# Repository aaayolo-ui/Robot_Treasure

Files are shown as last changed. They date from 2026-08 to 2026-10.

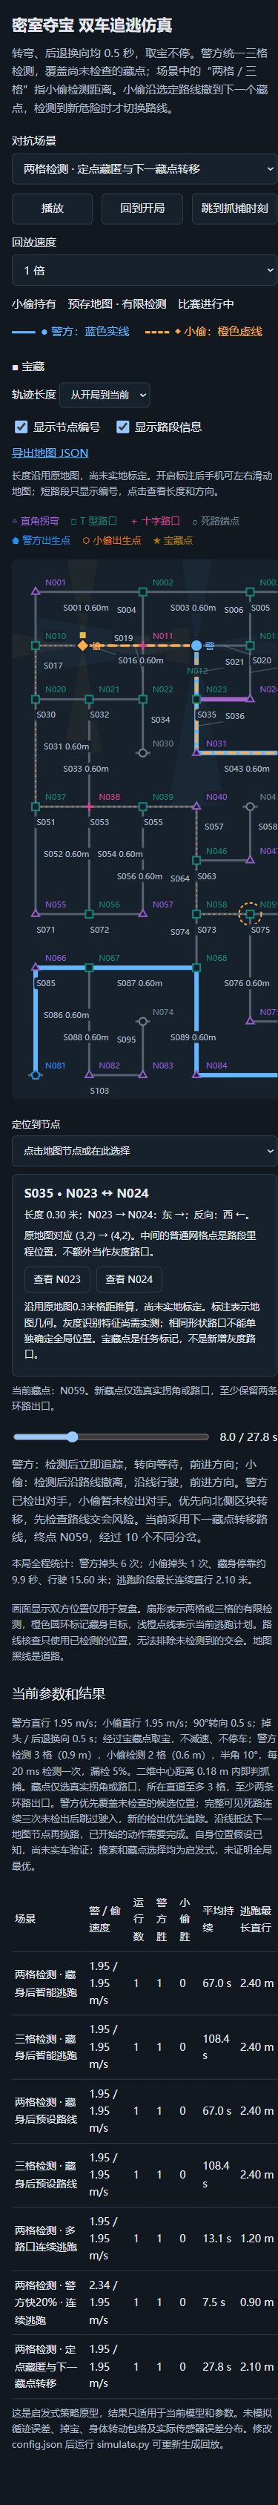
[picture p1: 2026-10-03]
Tools/TreasurePursuitSimulator/qa/annotations-mobile.jpg

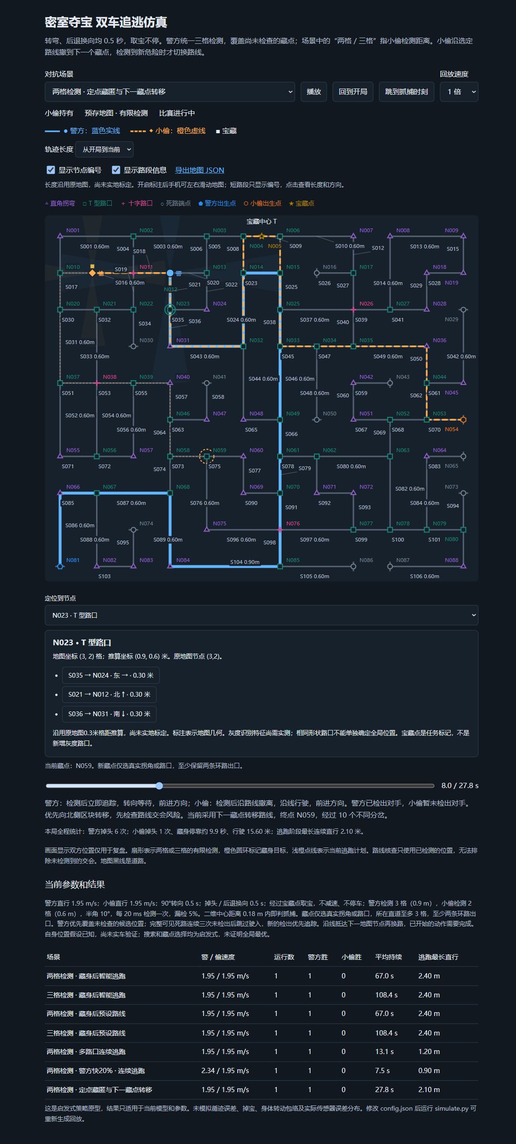
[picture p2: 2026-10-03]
Tools/TreasurePursuitSimulator/qa/annotations-desktop.jpg

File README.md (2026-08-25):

# Robot_Treasure

基于 STM32 的四轮差速自主移动机器人，用于 2026 江苏省大学生机器人大赛“密室夺宝”项目。

## 项目基线

项目以稳定循迹、可靠路口判断和可恢复故障处理为优先级，不追求极限速度。系统不使用 Jetson、摄像头、YOLO 或 ROS。

| 项目 | 当前确定方案 |
|---|---|
| 主控 | STM32F103RCT6 开发板 |
| 底盘 | R5 铝合金四驱底盘，2 mm 铝合金底板，约 190 mm × 198 mm × 72 mm |
| 动力 | MC520P30_12V 永磁有刷编码器减速电机 ×4，配 65 mm 黑色大摩擦力轮胎 ×4 |
| 驱动 | MD240A 四路 TB6612FNG 编码器电机驱动板 ×1；四个通道分别驱动四个车轮 |
| 电源 | LB326E 12 V 2600 mAh 3S 锂电池、12.6 V 1.5 A 配套充电器、3 A 多路 DC-DC |
| 循迹 | NCHD12 12 路灰度传感器 ×2，经同一条 I²C 总线连接 |
| 对手检测 | AI-1811 单模块基础 UART 读取已完成；前、后、左、右四方向的多模块方案尚未最终锁定 |
| 机构与提示 | 前后黑色 ABS 板、强力磁铁、LED、有源蜂鸣器 |

## 关键控制原则

- 前 NCHD12 是前进循迹和主要路口判断的默认输入；后 NCHD12 用于后退循迹和逃跑模式。
- 前、后模块保留独立数据和物理方向，不能简单拼成横向连续 24 路；默认不运行两个相互冲突的独立循迹 PID。
- 四个电机独立输出、独立编码器反馈；基础阶段同侧前后轮可使用相同目标速度，但不能并联到同一驱动通道。
- 电机的额定理论线速度约 0.99 m/s，初期软件目标速度限制在约 0.3～0.5 m/s，并采用 PWM 限制、斜坡和速度闭环。

## 供电关系

```text
3S 锂电池
    │
    ├── 总开关 ── 保险丝 ── 动力支路 ── MD240A ── Motor_FL / Motor_RL / Motor_FR / Motor_RR
    │
    └── 控制支路 ── 3A 多路 DC-DC
                         ├── 5V → STM32 开发板及 5V 传感器
                         └── 3.3V → 编码器及 3.3V 模块
```

电机仅由电池直接向 MD240A 的 VM 端供电，不能经过 DC-DC。整车所有模块必须共地；MD240A 板载 3.3 V / 5 V 不作为整车主要控制电源，两个稳压模块的输出不得直接并联。

## 状态与下一步

已购买：R5 铝合金四驱底盘、MC520P30_12V 编码器电机 ×4、65 mm 黑色轮胎 ×4、前后黑色 ABS 板、AI-1811 ToF 激光测距模块 ×1、USB 转 TTL 模块 ×1。USB 转 TTL 用于电脑串口测试；12B 已将 AI-1811 直接连接 STM32 完成单模块基础读取。

已完成技术选型、但购买状态须按项目记录确认：MD240A、LB326E 电池、配套充电器、3 A 多路 DC-DC、NCHD12 ×2。STM32F103RCT6 开发板与 ST-Link V2 的实际购买状态也仍需项目记录确认。

当前敌方检测仍处于方案验证阶段：AI-1811 单模块的 UART 通信、帧格式、校验和距离字段已完成实物原始数据验证；普通红外单路接口（12A，`VCC→3.3V`、`OUT→PB14`、低电平有效）已完成近距离障碍/物体检测基础验证，并在 13A 完成“连续障碍检测→停车约 200 ms→30 RPM 后退约 1 s→自动停车”的基础车辆联动验证。
普通红外仍暂时作为备用和对比测试使用，不代表最终敌方机器人检测、最终安装或最终整车方案；前、后、左、右四方向的多模块数量、安装及通信方案仍待后续验证，距离精度标定未执行。

## 文档

- [总体方案设计](Docs/03_总体方案设计.md)
- [硬件清单](Docs/04_硬件清单.md)
- [STM32 软件架构设计](Docs/05_STM32软件架构设计.md)
- [开发记录](Docs/06_开发记录.md)
- [团队协作与 Git 分支说明](Docs/07_团队协作与Git分支说明.md)

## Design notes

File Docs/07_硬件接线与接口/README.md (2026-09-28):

# Robot_Treasure 硬件接线与接口

本目录是项目级的实体接线、STM32 引脚占用与扩展规划的唯一维护入口；不属于任何单一测试工程，也不存放硬件驱动代码。
当前灰度方向参考工程为 [`Gray12_VehicleDirection_Test`](../../STM32/Keil_Project/Gray12_VehicleDirection_Test)，已完成 11C 灰度安装方向与车辆横向误差符号实机确认。
AI-1811 单模块基础 UART 读取的历史参考工程为 [`Laser12B_AI1811_Raw_Uart_Test`](../../STM32/Keil_Project/Laser12B_AI1811_Raw_Uart_Test)；当前整车不再使用该模块，原 PA3 占用已经释放。
普通红外已由 [`Infrared_Raw_Test`](../../STM32/Keil_Project/Infrared_Raw_Test) 完成 12A 基础读取，并由 [`Infrared13A_ObstacleReverse_Test`](../../STM32/Keil_Project/Infrared13A_ObstacleReverse_Test) 完成基础障碍触发后退联动验证。

## 当前基线

台架已使用的供电路径为：3S 锂电池正、负极分别接入 MD240A `VIN/VM`、`GND`；MD240A `VOUT 5V`、`GND` 分别接入 STM32 开发板 `5V`、`GND`；STM32 `5V/GND` 再接第一块 NCHD12 的 `VCC/GND`。四路电机、四路编码器、第一块 NCHD12、CH340 调试串口、ST-Link SWD 与板载按键均已有实际连接或实机验证记录，详见下表文档。

```text
3S 电池 ──> MD240A VIN/VM ──> 四路电机
                 │ VOUT 5V
                 └────────────> STM32 5V ──> NCHD12(0x20)
所有已连接模块 GND ───────────────────────> 共地
```

### 11C/11D 当前车辆坐标与单轮方向基线

- 当前车头为 11C 重新定义后的车头；物理轮位为 FL=B、FR=A、RL=D、RR=C。
- 灰度模块 P12 侧对应 `VEHICLE_LEFT`，P1 侧对应 `VEHICLE_RIGHT`。
- 灰度标签坐标保持 P1 侧为负、P12 侧为正；车辆横向误差使用 `vehicle_error_x100 = -label_position_x100`，即车辆左为负、右为正。
- 11D-1 已实机确认车辆前进方向：B/FL→ELEC_REV、A/FR→ELEC_REV、D/RL→ELEC_FWD、C/RR→ELEC_FWD；车辆后退使用相反电气方向。
- 前进时原始编码器符号对应逻辑符号为 B/D=+1、A/C=-1。11D-2 已实机确认新车头下的前进直行：左侧分组 B+D、右侧分组 A+C，四轮独立速度 PI 在目标最终 80 RPM 下稳定至约 77～79 RPM，整体左右平均转速差约 0.2 RPM，无长期 PI 饱和；后退、转向和循迹闭环仍待独立验证。
- PWM=180/999 的单轮测试下，四路均可连续转动；没有 B 专用固定 PWM 补偿。旧测试工程及其历史阶段记录可能使用旧车头映射，不能直接作为当前轮位控制基线。
- 12A/13A 已实机确认普通红外单路接口为 `VCC→3.3V`、`GND→GND`、`OUT→PB14`；PB14 使用 `GPIO Input`、`GPIO_NOPULL`，低电平表示 `DETECTED`、高电平表示 `CLEAR`。
  13A 已验证连续障碍检测可触发一次“停车约 200 ms→30 RPM 后退约 1 s→自动停车”的基础联动；该引脚仍仅为测试接口，不是最终整车永久分配。
- 当前计划保留 PB14 作为前向红外，并新增左/后/右三路普通红外：左 `PA3`、后 `PB15`、右 `PA11`。三路新增分配均尚未接线验证；PA11、PB15 接线前还须确认开发板实体引出。

## 文档导航

- [01_已验证硬件接线总表.md](01_已验证硬件接线总表.md)：已连接且已使用或验证的供电、模块与信号接线；AI-1811 条目仅保留历史验证事实，并注明当前已拆除。
- [02_STM32引脚占用总表.md](02_STM32引脚占用总表.md)：以最新参考工程 `.ioc` 为准的 STM32 引脚占用。
- [03_后续硬件扩展预留.md](03_后续硬件扩展预留.md)：尚未接入或尚未验证的硬件计划，不能当作现状使用。

## 状态说明

| 状态 | 定义 |
|---|---|
| 已实机验证 | 已实际接线，并有实机测试或可追溯验证记录。 |
| 已连接但具体参数待确认 | 接线/信号已使用，但电压、极性、针序等参数尚无独立可靠记录。 |
| 仅软件配置 | 当前 `.ioc` 或代码配置了资源，不单独代表实体接线已完成。 |
| 仅后续计划 | 尚未实机接入和验证；只能记录在 `03` 中。 |

## 修改规则

- 新增硬件前先检查 [02_STM32引脚占用总表.md](02_STM32引脚占用总表.md)，不得直接使用已占用引脚。
- 改动引脚时必须同步修改 `.ioc`、源代码驱动和本目录文档。
- 未完成实机测试的接线只能写入 `03`；完成实机测试后，才能移入 `01`。
- 文档与实物不一致时，停止上电并重新核对；不得凭猜测接线。

## 安全规则

- 所有模块必须共地；禁止带电插拔 I2C、编码器和电源线。
- 当前由 MD240A `VOUT 5V` 给 STM32 供电时，外部 DC-DC 输出不得同时并联到 STM32 `5V`。
- 电池 `VIN/VM` 不得接入 STM32；电机动力电源不得经过 STM32 或外部 5V 降压输出。
- CH340 只接串口信号和 GND 时，不接其 `5V/3.3V` 输出；ST-Link、CH340、MD240A VOUT 与后续 DC-DC 不能同时作为 STM32 供电源。

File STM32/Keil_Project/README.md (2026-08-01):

# Keil_Project

用于存放 Keil5 工程文件。

## 后续操作

`CubeMX 生成工程 → 使用 Keil5 打开 → 添加 User/Hardware/Algorithm/Control 文件 → 编译 → ST-Link 下载`

> 当前未指定 STM32 型号，因此暂不创建 `.uvprojx` 工程。

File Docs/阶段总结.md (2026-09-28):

# 阶段总结

本文件按开发顺序记录阶段结论。除明确标为实机确认的内容外，其余仅代表工程实现或编译状态，不补写缺失的硬件测试事实。

## 01｜Motor_A_Test

### 对应工程

`STM32/Keil_Project/Motor_A_Test`

### 阶段目标

建立 A 路电机正转、反转、停止和驱动使能的基础测试。

### 关键配置

电机驱动默认停止，PWM 为 0，驱动板默认禁用；方向切换需先停止。

### 实际测试结果

本次汇总未检索到可独立引用的原始硬件测试记录。

### 已知问题

硬件测试原始数据待后续补录。

### 最终结论

部分通过：基础工程已完成；进入下一阶段前应保留并补充对应的实机记录。

### 下一阶段

Motor_A_Encoder_Test。

## 02｜Motor_A_Encoder_Test

### 对应工程

`STM32/Keil_Project/Motor_A_Encoder_Test`

### 阶段目标

验证 A 路编码器计数、方向和转速计算基础。

### 关键配置

采用定时器编码器模式，转速以整数 `rpm_x10` 表示。

### 实际测试结果

本次汇总未检索到可独立引用的原始硬件测试记录。

### 已知问题

硬件测试原始数据待后续补录。

### 最终结论

部分通过：编码器基础工程已完成；需以原始实测记录补充硬件结论。

### 下一阶段

Motor_A_PwmRpm_Test。

## 03｜Motor_A_PwmRpm_Test

### 对应工程

`STM32/Keil_Project/Motor_A_PwmRpm_Test`

### 阶段目标

观察 A 路电机 PWM 与转速的关系，为闭环参数选择提供基础。

### 关键配置

使用 A 路电机和编码器的 PWM/RPM 测试链路。

### 实际测试结果

已实际观察到：B 电机在相同开环 PWM 下较慢；该现象已转入 P001 持续观察。

### 已知问题

B 的偏慢原因尚未完全确认。

### 最终结论

部分通过：PWM/RPM 对比为后续独立闭环提供了依据。

### 下一阶段

Motor_A_SpeedPid_Test。

## 04｜Motor_A_SpeedPid_Test

### 对应工程

`STM32/Keil_Project/Motor_A_SpeedPid_Test`

### 阶段目标

验证单电机定点速度 PI 控制。

### 关键配置

Kp=0.80、Ki=0.25；定点计算、积分限幅、防积分饱和；控制周期 100 ms。

### 实际测试结果

已实机验证通过的 PI 算法、参数、启动处理、停止积分清零和目标/测量单位，后续被四轮工程复用。

### 已知问题

本次汇总未包含该阶段完整原始串口曲线。

### 最终结论

通过：可进入四路底盘模块化阶段。

### 下一阶段

Four_Motor_Base。

## 05｜Four_Motor_Base

### 对应工程

`STM32/Keil_Project/Four_Motor_Base`

### 阶段目标

建立四路电机、四路编码器及安全默认状态的模块化基础。

### 关键配置

四路 PWM、编码器和驱动板 STBY；上电 PWM=0、方向 GPIO 为低、驱动禁用。

### 实际测试结果

已统一采用 1560 count/rev；B 的人工标定约 1565.1 count/rev，差异较小。

### 已知问题

B 的偏慢并非主要由编码器每圈计数差异造成，见 P001、P002。

### 最终结论

通过：可进入四路通道测试。

### 下一阶段

Four_Motor_Channel_Test。

## 06｜Four_Motor_Channel_Test

### 对应工程

`STM32/Keil_Project/Four_Motor_Channel_Test`

### 阶段目标

验证四路电机与四路编码器通道的独立性。

### 关键配置

每个硬件编码器 delta 在一个采样周期内仅读取一次；各通道独立显示与控制。

### 实际测试结果

本次汇总未检索到可独立引用的原始硬件测试记录。

### 已知问题

原始通道测试数据待后续补录。

### 最终结论

部分通过：工程已作为后续底盘工程的来源；硬件原始记录仍需补充。

### 下一阶段

Four_Motor_Chassis_Test。

## 07｜Four_Motor_Chassis_Test

### 对应工程

`STM32/Keil_Project/Four_Motor_Chassis_Test`

### 阶段目标

确认四轮车体逻辑方向、物理轮位和编码器符号。

### 关键配置

FL=D、FR=C、RL=B、RR=A；逻辑前进时 D/C 电气正转、B/A 电气反转；A=-1、B=+1、C=-1、D=+1。

### 实际测试结果

该方向映射与逻辑编码器符号已作为后续四轮闭环和落地测试的验证基础。

### 已知问题

未在本次汇总中补录各动作的原始实测数据。

### 最终结论

通过：可进入四轮独立速度闭环阶段。

### 下一阶段

Four_Motor_SpeedPid_Test（10E）。

## 08｜Four_Motor_SpeedPid_Test（10E）

### 对应工程

`STM32/Keil_Project/Four_Motor_SpeedPid_Test`

### 阶段目标

建立四个相互独立的车轮速度 PI 控制器，并验证前进、后退与原地转向的逻辑速度符号。

### 关键配置

四个独立 PI 实例；Kp=0.80、Ki=0.25、100 ms 控制周期；四轮反馈和逻辑 PWM 均由 Chassis 层统一映射。

### 实际测试结果

四轮独立速度 PI 已实机验证；停止/禁用状态下的反馈刷新已统一，单轮速度与左右平均值使用同一 Chassis 反馈帧。

### 已知问题

紧急停止后首帧可能显示实际惯性速度，见 P004。

### 最终结论

通过：可进入落地低速直线测试。

### 下一阶段

Four_Motor_GroundStraight_Test（10F）。

## 09｜Four_Motor_GroundStraight_Test（10F）

### 对应工程

`STM32/Keil_Project/Four_Motor_GroundStraight_Test`

### 阶段目标

在底盘落地条件下观察四轮独立闭环前进、后退、起停安全性和左右速度差异。

### 关键配置

- 前进四轮目标：+80.0 RPM；后退四轮目标：-80.0 RPM。
- 软启动：4.0 RPM / 100 ms，0 到 80 RPM 约需 2.0 秒。
- PWM 测试上限：300；最大运行时间：3 秒，到时自动停止。
- Kp=0.80，Ki=0.25，控制周期=100 ms，堵转持续时间=1500 ms。
- 停止或禁用时 PI 清零但编码器反馈继续更新；不使用 B 轮或左右固定补偿。

### 实际测试结果

- 前进方向正确，后退方向正确。
- 前进约 50 cm 时向右偏约 2～3 cm。
- 后退向左后方返回，轨迹大致回到原来的位置。
- 未出现原地旋转、单轮反转或明显失控。

### 已知问题

存在稳定轻微右偏，当前可接受，见 P005。

### 最终结论

通过：可以进入灰度传感器基础读取阶段。

### 下一阶段

11A｜灰度传感器基础读取测试。

## 10｜11A｜12路灰度传感器 I2C 基础读取与通道映射

### 对应工程

`STM32/Keil_Project/Gray12_I2C_BasicRead_Test`

### 阶段目标

验证 12 路灰度模块的 I2C 基础通信、物理通道顺序、黑白极性和黑色通道数量统计，并保持电机处于安全禁用状态。

### 关键配置

- I2C1 使用 PB8/PB9 重映射，频率为 100 kHz；模块 7 位地址为 `0x20`，HAL 调用使用 `addr7 << 1`。
- 使用 PCA9555-compatible 访问方式：输入配置寄存器为 `0x06`、`0x07`，输入数据寄存器为 `0x00`、`0x01`。
- `RAW16` 为完整 16 位原始数据，`GRAY12 = RAW16 & 0x0FFFU`；B12～B15 不属于灰度通道。
- 通道映射为 P1=B0、P2=B1，依次至 P12=B11；黑色=1，白色=0。
- 结构分层：Core 仅保留 CubeMX 外设初始化和 App 调用；Hardware 包含 MotorDriver、Encoder、Key、NCHD12、UartDebug；User 为 `App_Gray12BasicRead`。
- 电机安全状态：Driver 禁用、STY 低电平、四路 PWM 为 0，未启动速度 PI。

### 实际测试结果

- 全白：`RAW16=0xF000`、`GRAY12=0x000`、`BLACK_COUNT=0`，P1～P12 均为 0。
- 全黑：`RAW16=0xFFFF`、`GRAY12=0xFFF`、`BLACK_COUNT=12`，P1～P12 均为 1。
- 仅 P1 为黑：`GRAY12=0x001`、`BLACK_COUNT=1`。
- 仅 P6 为黑：`GRAY12=0x020`、`BLACK_COUNT=1`。
- 仅 P12 为黑：`GRAY12=0x800`、`BLACK_COUNT=1`。
- 串口输出正常，P1～P12 通道顺序和 `BLACK_COUNT` 统计正确，灰度数据变化与模块指示灯一致。
- 测试全过程电机未运动；Keil 编译结果为 0 Error(s)、0 Warning(s)。

### 已知问题

曾发生设备地址可应答但 PCA9555-compatible 寄存器读写失败的情况；最终复测未持续出现，唯一根本原因尚未确认，详见 P007。

### 最终结论

通过：已完成硬件验证，可以进入后续灰度位置计算阶段。

### 下一阶段

灰度位置计算基础验证（加权位置算法）。

## 11｜11B｜12路灰度位置与横向误差计算

### 对应工程

`STM32/Keil_Project/Gray12_Position_Test`

### 阶段目标

基于 11A 已验证的单块 NCHD12 读取结果，验证 12 路二值灰度的加权位置、相对传感器中心的横向误差、无黑线和全黑状态判断；本阶段不执行巡线 PID、车轮差速修正、丢线搜索或路口识别。

### 软件结构与关键配置

- 工程以已验证可下载的 `Gray12_I2C_BasicRead_Test` 为完整模板复制，保留 `.uvprojx`、`.uvoptx`、ST-Link、SWD、Flash Algorithm 与下载配置；未修改引脚、时钟、I2C、USART、电机或编码器硬件配置，`.ioc` 仅改项目名称和文件名。
- `Core` 保留 CubeMX 初始化和 App 调用；`Hardware` 保留 MotorDriver、Encoder、Key、NCHD12、UartDebug；新增 `System/SystemTime`、纯算法 `Algorithm/GrayPosition` 和 `User/App_Gray12Position`。
- `GrayPosition` 不包含 HAL，不访问 I2C、GPIO、UART、定时器或电机，不使用 `float` 或 `double`；输入仅使用 `gray12` 低 12 位。
- 一个探头间距定义为 `100`，权重依次为：P1=-550、P2=-450、P3=-350、P4=-250、P5=-150、P6=-50、P7=+50、P8=+150、P9=+250、P10=+350、P11=+450、P12=+550。
- 坐标为传感器标签坐标：P1 一侧为负、P12 一侧为正，P6/P7 之间为 0；尚未绑定到车辆左/右方向。
- 黑色通道权重求和后除以黑色通道数量得到 `POSITION_X100`；中心目标为 0，因此 `ERROR_X100 = POSITION_X100`。
- `GRAY12=0x000` 为 `NO_LINE`、`VALID=0`；黑色通道数量 1～11 为 `VALID`、`VALID=1`；`GRAY12=0xFFF` 为 `ALL_BLACK`、`VALID=0`。无黑线和全黑均不伪装为有效中心位置。

### 软件自检与编译结果

- 9 组软件向量全部通过：`0x000`、`0x001`、`0x020`、`0x040`、`0x060`、`0x030`、`0x0C0`、`0x800`、`0xFFF`。
- Keil 使用 ARM Compiler 5.06 编译，结果为 0 Error(s)、0 Warning(s)，已生成 AXF 和 HEX。

### 实际测试结果

- 全白时输出 `STATUS=NO_LINE`、`VALID=0`；全黑时输出 `STATUS=ALL_BLACK`、`VALID=0`。
- 仅 P1 黑时 `POSITION_X100/ERROR_X100=-550`；仅 P6 黑时为 `-50`；P6/P7 同时黑时为 `0`；仅 P7 黑时为 `+50`；仅 P12 黑时为 `+550`，状态均符合预期。
- 黑线从 P1 一侧缓慢移动至 P12 一侧时，位置由负值经 0 向正值连续变化，整体方向正确，未发现突然反向跳变。
- 测试过程中电机未运动，STY/STBY 保持低电平、四路 PWM 保持 0；未运行速度 PI、巡线 PID，也未根据灰度误差控制车轮。

### 最终结论

通过：已完成单块12路灰度模块的位置与横向误差基础计算验证，可以进入车辆安装方向确认及灰度误差与车体方向关系验证阶段。

## 12｜11C｜灰度传感器安装方向与车辆横向误差符号确认

### 对应工程

`STM32/Keil_Project/Gray12_VehicleDirection_Test`

### 阶段目标

在 11B 已验证的灰度标签坐标基础上，锁定新车头下的灰度安装方向，并确认标签坐标转换为车辆横向误差后的符号正确；本阶段不实现新车头下的底盘映射或循迹控制。

### 软件结构与关键配置

- 工程结构为 `Core`（CubeMX 初始化与 App 调用）、`Hardware`（MotorDriver、Encoder、Key、NCHD12、UartDebug）、`Algorithm`（GrayPosition、GrayCoordinate）、`System`（SystemTime）和 `User`（App_Gray12VehicleDirection）。
- GrayPosition 保持标签坐标：P1=-550、P2=-450、P3=-350、P4=-250、P5=-150、P6=-50、P7=+50、P8=+150、P9=+250、P10=+350、P11=+450、P12=+550；P6/P7 之间为 0。
- 唯一安装方向配置为 `GRAY_MOUNT_P12_LEFT_P1_RIGHT`：P12 侧为车辆左侧，P1 侧为车辆右侧。
- 车辆坐标定义为左负、中心零、右正，转换规则为 `vehicle_error_x100 = -label_position_x100`。
- `NO_LINE` 与 `ALL_BLACK` 均保持 `LABEL_POSITION=INVALID`、`VEHICLE_ERROR=INVALID`，不伪造有效的零误差。

### 软件自检、编译与实机结果

- GrayPosition 自检为 `9/9 PASS`；GrayCoordinate 自检为 `PASS`，覆盖 UNKNOWN、两种安装方向以及 P12_LEFT_P1_RIGHT 下的 +550、0、-550 转换。
- ARM Compiler 5.06 编译结果为 0 Error(s)、0 Warning(s)，已生成 AXF 和 HEX；程序已下载并完成实机运行确认。
- P12 侧黑线时，`LABEL_POS_X100` 为正、`VEHICLE_ERROR_X100` 为负、`VEHICLE_SIDE=VEHICLE_LEFT`；中心时二者均为 0、`VEHICLE_SIDE=CENTER`；P1 侧时标签位置为负、车辆误差为正、`VEHICLE_SIDE=VEHICLE_RIGHT`。
- 运行期间电机未运动，STY/STBY 保持低、四路 PWM 为 0；未运行速度 PI、巡线 PID，也未根据车辆误差控制车轮。

### 新车头与物理轮位

从 11C 开始，原车尾重新定义为当前车头。已确认的物理轮位为 FL=B、FR=A、RL=D、RR=C；对应地，驱动通道 A=新右前 FR、B=新左前 FL、C=新右后 RR、D=新左后 RL，编码器 A/B/C/D 分别随对应电机处于相同物理轮位。

以下结论仍待独立验证，不能从旧车头下的结果推导：各通道“前进”的电气方向、编码器逻辑符号、前进/后退/左转/右转动作、左右轮速度分组、速度 PI 映射以及灰度误差到左右轮修正的控制方向。

### 最终结论

通过：已确认新车头下 P12 侧对应车辆左侧、P1 侧对应车辆右侧，车辆横向误差满足左负、中心零、右正。当前物理轮位已更新为 FL=B、FR=A、RL=D、RR=C；进入电机循迹前，必须重新验证新车头下的电机方向、编码器符号和底盘动作映射。

## 13｜11D-1｜新车头下单轮电气方向与编码器原始符号验证

### 对应工程

`STM32/Keil_Project/NewFront_MotorEncoder_Direction_Test`

### 阶段目标

逐通道验证新车头下 A/B/C/D 的物理轮位、电气方向与未经逻辑修正的编码器原始增量，为后续底盘映射提供已测数据；本阶段不运行速度 PI、整车自动运动或循迹控制。

### 已确认配置与实测结果

- 当前轮位为 B=FL、A=FR、D=RL、C=RR。
- 车辆前进的电气方向为：B/FL→ELEC_REV、A/FR→ELEC_REV、D/RL→ELEC_FWD、C/RR→ELEC_FWD；车辆后退使用相反电气方向。
- 车辆前进时编码器原始增量和逻辑符号为：B 原始为正、SIGN=+1；A 原始为负、SIGN=-1；D 原始为正、SIGN=+1；C 原始为负、SIGN=-1。
- 代表性原始增量为：B-FWD=-858、B-REV=+918；A-FWD=+1028、A-REV=-1027；C-FWD=-1045、C-REV=+990；D-FWD=+1015、D-REV=-1015。电气方向名称仅描述 IN1/IN2 组合，车辆物理方向以新车头观察结果为准。
- PWM=180/999（约 18%）时，四路均可连续转动；不存在 B 专用固定 PWM 补偿。旧工程中的 B 偏慢处理为四轮独立速度 PI 调节，不是 B 固定偏置。

### 软件与安全状态

- `NewFrontDirectionMap` 在 User 上层作为唯一方向/符号配置源，记录车辆方向到 ELEC_FWD/ELEC_REV 的映射及编码器逻辑符号；MotorDriver 底层电气定义保持不变。
- 保留 KEY1 选择 B/A/D/C、KEY2 切换 ELEC_FWD/ELEC_REV、WK_UP 长按 1000 ms 执行单轮测试的安全流程；每次仅一个通道、PWM=180、最长 800 ms，任意按键可中止并关闭 STY/STBY。
- ARM Compiler 5.06 编译结果为 0 Error(s)、0 Warning(s)，生成 AXF 和 HEX；程序已完成实机单轮验证。

### 后续边界

本阶段只确认单轮车辆前进方向与编码器逻辑符号。整车前进/后退/转向动作、左右轮速度分组、速度 PI 和灰度闭环控制仍须在后续独立阶段实现与验证。

### 最终结论

通过：新车头下四路单轮电气方向和编码器逻辑符号均已实测确认，可作为后续底盘方向重验的输入基线；不得将其直接等同于已完成整车控制验证。

## 14｜11D-2｜新车头下四轮 PI 落地直行验证

### 对应工程

`STM32/Keil_Project/NewFront_FourMotor_GroundStraight_PI_Test`

### 阶段目标

在 11D-1 已确认的新车头方向与编码器符号基线上，验证四轮独立速度 PI 的落地前进直行能力；本阶段不验证后退、转向或灰度循迹。

### 已确认配置

- 物理轮位为 B=FL、A=FR、D=RL、C=RR；前进电气方向为 B/A=ELEC_REV、D/C=ELEC_FWD；前进逻辑编码器符号为 B/D=+1、A/C=-1。
- 左侧分组为 B(FL)+D(RL)，右侧分组为 A(FR)+C(RR)；四轮各自使用独立速度 PI，未使用左右共用 PI。
- PI 参数为 Kp=0.80、Ki=0.25，最终目标为 80 RPM，目标斜坡为每 100 ms 增加 4 RPM，PWM 上限为 300，单次最长运行 3 秒。
- B 不存在固定 PWM 补偿；其输出仅由 B 自己的 PI 控制器调节。
- 测试数据每 100 ms 保存至固定 32 组 RAM 记录；停止后保持供电并重新连接 CH340 时，可按 KEY1 打印上一轮完整记录及汇总。新一轮测试会覆盖旧记录。

### 实机结果

- 小车在落地 3 秒前进测试中目测基本直行；最终目标 80 RPM，四轮最终约为 77～79 RPM。
- `LEFT_RIGHT_DIFF_RPM` 的整体统计约为 0.2 RPM；四路均未出现长期 PI 饱和。
- `B_MAX_PWM=246`，低于 PWM 上限 300；B 无固定补偿，四路均为独立 PI。

### 安全与编译

- 上电时电机保持关闭；KEY2 开始或正常停止，WK_UP 紧急停止，运行中 KEY1 立即停止；超时后四路 PWM 清零并关闭 STBY。
- ARM Compiler 5.06 全量编译结果为 0 Error(s)、0 Warning(s)，已生成 AXF 和 HEX；本次依据实机记录完成结果整理。

### 最终结论

通过：新车头下的四轮独立 PI 前进直行已完成落地验证，可作为后续底盘控制的前进直行基线。后退、转向和灰度循迹闭环仍需单独验证。

## 15｜11E｜新车头下单灰度 P 循迹验证

### 对应工程

`STM32/Keil_Project/NewFront_Gray12_LineFollow_P_LongRun_Test`

### 阶段目标

在 11C 的单灰度车辆横向误差方向和 11D-2 的四轮独立速度 PI 前进基线上，验证单灰度横向误差接入左右差速后的基础落地循迹链路；本阶段仅使用 P 修正，不宣称已经完成长期稳定循迹。

### 已确认配置与实测事实

- 单灰度安装方向为 P12 在车辆左侧、P1 在车辆右侧；车辆误差定义保持左负、中心零、右正。
- 左侧车轮分组为 B(FL)+D(RL)，右侧车轮分组为 A(FR)+C(RR)；四轮继续使用独立速度 PI，未加入 B 专用固定 PWM 补偿。
- P 循迹链路使用 `BASE_RPM=40`，并保留 100 ms 控制周期、RAM 脱线日志、无黑线/全黑/宽黑状态安全停车和按键停止逻辑。
- 实机观察到：车辆左偏时能够向中心修回，说明单灰度误差方向、差速方向和基础 P 控制链路可工作。
- 右偏修正时，`Kp=0.020` 和 `Kp=0.015` 均观察到车辆到达中心后仍继续穿越中心，形成明显的反向误差；该现象为后续 PD/PID 与双灰度方案提供了实测依据。

### 结论与后续边界

部分通过：单灰度 P 循迹已完成基础方向和修正能力验证，但尚未达到“完全稳定”的结论。纯 P 在右偏修正后存在穿越中心的过冲，后续应在独立开发工程中验证 D、I 以及前后双灰度的控制效果。`NewFront_Gray12_LineFollow_P_LongRun_Test` 已完成本阶段代码与编译整理；实机结论仅限上述已观察事实。

## 16｜12A｜普通红外传感器基础读取测试

### 对应工程

`STM32/Keil_Project/Infrared_Raw_Test`

### 阶段目标

验证普通红外模块单路数字输出的基础读取和电平含义，为近距离障碍/物体检测保留基础输入；本阶段不判断 ABS、材质或敌方机器人，也不确定最终整车检测方案。

### 实物接线与软件配置

- 普通红外模块 `VCC→3.3V`、`GND→GND`、`OUT→PB14`。
- PB14 配置为 `GPIO Input`、`GPIO_NOPULL`；当前工程每 200 ms 读取一次原始电平并通过 USART3 输出 `IR_RAW=1/0`。
- `IR_RAW=1` 表示 `CLEAR`；`IR_RAW=0` 表示 `DETECTED`，当前模块为低电平有效。
- PB14 仅作为 12A 单路基础测试接口，不代表最终整车永久引脚分配。

### 实物测试结果

- 在当前电位器设置下，白色目标、黑色非亮面目标置于约 10 cm 处均可稳定触发。
- 连续串口采样未观察到明显抖动。

### 软件与验证边界

- ARM Compiler 5.06 update 5（build 528）全量编译结果为 `0 Error(s)、0 Warning(s)`，已生成 AXF 和 HEX。
- 本阶段结论仅为当前台架条件下的近距离障碍/物体检测基础验证通过；未验证最终安装高度、角度、最终检测距离、比赛调参，也不据此宣称能够识别 ABS、材质或敌方机器人。

### 最终结论

通过：已完成普通红外传感器单路 GPIO 基础读取和当前条件下的近距离障碍/物体检测基础验证；普通红外是否纳入最终整车方案及其永久安装、引脚分配仍待后续决定。

## 17｜12B｜AI-1811 激光测距基础读取测试

### 对应工程

`STM32/Keil_Project/Laser12B_AI1811_Raw_Uart_Test`

### 阶段目标

验证单个 AI-1811 的供电、主动上报 UART 接收、原始帧结构、校验和距离字段读取，为后续粗略距离/阈值判断保留可靠输入；本阶段不进行毫米级精度标定，不新增 Modbus 或传感器发送逻辑。

### 实物接线与通信结论

- AI-1811 `V→3.3V`、`G→GND`、`T→PA3/USART2_RX`，`R` 当前不接。
- USART2 使用 115200、8N1、RX Only；PA2 不分配给 USART2_TX，继续保留现有电机 D 路 PWM 资源。
- USART3 使用 PB10/PB11、115200，继续作为 CH340 调试日志口。
- 模块为主动上报；实测连续稳定收到固定 8 字节帧：

  ```text
  AA 05 FW_L FW_H DIST_L DIST_H CONF SUM
  ```

- `FW`、`DIST` 均为小端；`DIST` 单位为 mm；`SUM` 为前 7 字节累加和的低 8 位。原始帧结构、校验和距离变化均已由实物原始数据确认正常。

### 软件实现与验证边界

- 当前源码已实现正式帧解析：帧头/类型识别、固定长度接收、校验和检查、小端 `FW`/`DIST` 提取及 USART3 日志输出。
- ARM Compiler 5.06 全量编译结果为 0 Error(s)、0 Warning(s)。本次不下载；正式解析代码仅确认实现并编译通过，尚未新增解析版硬件运行结论。
- 本阶段没有执行距离精度标定或额外硬件测试；资料中原先记录的 9600 仅作为资料值保留，不能覆盖本次实物验证得到的 115200 正式项目结论。

### 最终结论

通过：AI-1811 单模块 UART 通信、PA3/USART2_RX 接收接口、115200 参数、8 字节帧格式、校验规则和距离字段已完成实物原始数据验证；正式解析代码已完成并通过编译。四个 ToF 的最终通信方案和距离精度标定仍未确定或执行。

## 18｜13A｜普通红外障碍检测触发后退基础联动

### 对应工程

`STM32/Keil_Project/Infrared13A_ObstacleReverse_Test`

### 阶段目标

在 12A 普通红外单路基础读取的已验证接口上，验证普通红外障碍检测能够安全触发一次基础车辆后退联动；本阶段不确定最终敌方机器人检测、最终安装或最终普通红外方案。

### 已确认配置与实测结果

- 普通红外继续使用 `VCC→3.3V`、`GND→GND`、`OUT→PB14`；PB14 为 `GPIO Input`、`GPIO_NOPULL`，低电平 `0` 表示 `DETECTED`、高电平 `1` 表示 `CLEAR`。
- 程序以 100 ms 控制周期统计连续检测；连续 3 次 `DETECTED` 后先清零目标并停车约 200 ms，再以 30 RPM 后退约 1 s，随后自动停车。
- 已实机完成并确认正常运行：`KEY2启动 → 30 RPM前进 → PB14连续检测到障碍 → 停车约200 ms → 30 RPM后退约1 s → 自动停车`。

### 软件安全与验证边界

- 源码保留 KEY1/WK_UP 立即停车、堵转停车和约 10 s 最长运行超时保护；这些是已有代码安全逻辑，本阶段未将其记为实机验证结果。
- ARM Compiler 5.06 update 5（build 528）全量编译结果为 `0 Error(s)、0 Warning(s)`。
- 本阶段仅证明普通红外已从基础读取进一步完成“障碍检测→车辆动作联动”的实机验证；未验证最终安装高度、角度、最终检测距离、比赛调参或敌方机器人/ABS/材质识别，也不据此确定最终整车红外方案。

### 最终结论

通过：普通红外 PB14 单路输入已完成基础障碍检测触发后退联动验证。已确认的行为仅限 KEY2 启动后 30 RPM 前进、连续障碍检测、约 200 ms 停车、约 1 s 后退和自动停车；最终传感器方案与安装仍待后续独立验证。

## 19｜14A｜单灰度循迹 + 普通红外障碍触发后退基础整合

### 对应工程

`STM32/Keil_Project/Infrared14A_LineFollow_ObstacleReverse_Test`

### 阶段目标

在 11E 单灰度 P 循迹和 13A 普通红外障碍后退的已验证基础上，验证红外障碍检测能够抢占循迹控制，并完成一次安全的停车、后退和自动停止流程；本阶段不进行 P/PID 调参，也不形成最终比赛策略。

### 已确认配置与实测结果

- 循迹部分保持 11E 新车头单灰度 P 基线：`BASE_RPM=40`、`Kp=0.015`、四轮独立速度 PI、轮位与方向映射均未重新调整。
- 普通红外继续使用 PB14 `GPIO Input`、`GPIO_NOPULL`，低电平 `0` 为 `DETECTED`、高电平 `1` 为 `CLEAR`；连续 3 次检测后优先抢占循迹。
- 已实机确认：KEY2 启动后能够运行现有单灰度 P 循迹；检测到前方障碍后可抢占循迹，随后正常完成停车约 200 ms、后退约 1 s 和自动停车，整体障碍联动运行正常。

### 循迹现象与验证边界

- 现有单灰度 P 循迹效果仍较差，存在明显偏移和稳定性不足；本阶段未重新调 P/PID，该现象不影响“红外障碍触发后退联动”整合验证通过的结论。
- 源码保留 KEY1/WK_UP 停止、灰度无黑线/全黑/宽黑、I2C、堵转和约 10 s 超时等安全逻辑；除上述已确认行为外，不将这些逻辑写为本阶段实机验证结果。
- 本阶段不验证 AI-1811、双灰度、自动转弯、后退后重新找线、敌我识别、最终安装或最终比赛策略。

### 最终结论

通过：普通红外障碍检测已完成对现有单灰度 P 循迹的优先级抢占与“停车约 200 ms→后退约 1 s→自动停车”基础整合验证。单灰度 P 循迹仍存在明显偏移和稳定性不足，不能表述为循迹效果良好或已完成最终调参。

## 20｜12 路双灰度侧边转弯循迹竞速基线（2026-09-28）

### 对应工程与范围

`STM32/Keil_Project/Gray12_SideTurn_LineFollow_Test`。本次保存该工程当前本地源码和调好的参数，作为后续红外避障整合前的可复现基线；不把尚未测试的红外避障逻辑写入本工程。

### 当前代码与实测反馈

- 代码中的循迹直线目标为 220 RPM，灰度位置 PID 的 Kp/Ki/Kd/Kh（x1000）为 75/8/7/5；转弯后找线初值 100 RPM，路口识别后以 100 RPM 受控前进 200 ms，再主动制动并进入陀螺仪转向。四轮速度 PI 的 PWM 上限为 800。
- 用户报告：这份已调参代码目前能在地图上以不错的速度和准确度运行。此结论限于当前循迹运行反馈，不等于红外避障功能已经完成或验证。
- JY61P 已由用户按此前相同接线重新连接；重新接线后的通信与转向尚待下一阶段实测确认。四个红外传感器的线已由用户接好，但具体引脚、极性及避障行为尚未在本阶段核实，当前循迹工程未接入红外逻辑。

### 提交边界

保留这一版本的源码与参数，不顺手加入新功能；后续避障试验优先从此基线单独复制工程，以便随时复现当前循迹效果。

## 提交前维护规则

每次准备提交和 push 前，检查本次修改所属阶段及问题状态，并同步更新本文件和《问题记录》。仅记录已确认的代码变化与硬件测试结果；未进行硬件测试时写明“仅编译通过，尚未完成硬件验证”。不删除有效历史记录，不把未来计划写成已完成，避免重复记录同一问题；文档更新应与本次代码一同提交。

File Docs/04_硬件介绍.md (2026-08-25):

# 硬件介绍与采购记录

本页记录已购硬件、购买链接、实际支付金额及已有资料链接。价格以本页记录为准，包含已明确列出的运费。

## 1. 开发板

- 名称：STM32F103RCT6 开发板（Type-C 口已焊接，带 1.44 寸 TFT 屏）
- 购买链接：[淘宝链接](https://e.tb.cn/h.84uw8D3SLZhhUBS?tk=BB7ygxPPIyO)
- 实付：￥49.80
- 资料链接：[新路城资料](https://www.xinlucity.com/?s=resourcedetail/index/id/234.html)

## 2. ST-Link

- 名称：STLINK-V2.1
- 购买链接：[淘宝链接](https://e.tb.cn/h.84FYnh01GahmPHJ?tk=RKBhgxPJ3qd)
- 实付：￥11.90
- 资料链接：[新路城资料](https://www.xinlucity.com/?s=resourcedetail/index/id/253.html)

## 3. 12 路数字灰度传感器

- 数量：2 个
- 购买链接：[淘宝链接](https://e.tb.cn/h.8fxVNS0AQb7ojnv?tk=WjwEgxPFo1H)
- 实付：￥291.40（￥266.40 + 运费 ￥25.00）
- 资料链接：[百度网盘](https://pan.baidu.com/s/1RLq9MH9iniR-h2vwI5AMXw?pwd=8888)，提取码：`8888`

## 4. 普通红外传感器

- 数量：4 个
- 定位：已购、备用和对比测试，不作为当前最终首选方案。
- 购买链接：[淘宝链接](https://e.tb.cn/h.85gp2qOAAhajMKc?tk=XSCdgxPxpmz)
- 实付：￥12.60
- 资料链接：[百度网盘](https://pan.baidu.com/s/1UErGk4y0h-6ww0Xs1XPRog)，提取码：`8888`

## 5. 小车底盘

- 配置：铝合金底板、65 mm 橡胶轮胎、MC520 编码电机。
- 购买链接：[淘宝链接](https://e.tb.cn/h.84FTcE9ZEy6Efaz?tk=upvjgxPAM0s)
- 实付：￥232.80（￥229.00 + 运费 ￥3.80）
- 资料链接：[百度网盘](https://pan.baidu.com/s/1GgmRw75_zlgiy0HDofT1Yw?pwd=rtyy)，提取码：`rtyy`

## 6. DC-DC 降压模块

- 参数：6–30 V 输入、5 V 输出、最大 3 A 电流负载。
- 购买链接：[淘宝链接](https://e.tb.cn/h.84eSurweyr6spFR?tk=TYEGgxEr3D6)
- 实付：￥10.71
- 资料链接：[新路城资料](https://www.xinlucity.com/?s=resourcedetail/index/id/316.html)

## 7. 杜邦线

- 配置：公对公、母对母、公对母各 21 cm，共 120 根。
- 购买链接：[淘宝链接](https://e.tb.cn/h.84Fmmj7ykvXQrV3?tk=RCAngxl54Pu)
- 实付：￥9.87

## 8. 电源

- 名称：3S 锂电池。
- 购买链接：[淘宝链接](https://e.tb.cn/h.8UfPvHoqkdCPidg?tk=NZE3gxEo7Ey)
- 实付：￥61.00

## 9. 电机驱动模块

- 购买链接：[淘宝链接](https://e.tb.cn/h.84e13z9PIimiE0v?tk=aSiggxESrUV)
- 实付：￥50.80（￥47.00 + 运费 ￥3.80）
- 资料链接：[百度网盘](https://pan.baidu.com/s/1zsBM7oMm_sbUlgKiRIafEQ?pwd=uhri)，提取码：`uhri`

## 10. AI-1811 ToF 激光测距模块

- 数量：1 个。
- 购买链接：[淘宝链接](https://e.tb.cn/h.85vNOUWAmMOlGvP?tk=voNDgCYsY48)
- 实付：￥29.80
- 用途：已完成 12B 单模块 STM32 基础 UART 读取；是否扩展到四方向仍待方案验证。

## 11. USB 转 TTL 模块

- 数量：1 个。
- 购买链接：[淘宝链接](https://e.tb.cn/h.8UQiFzKxz8FrMJD?tk=bPhagCYGWwk)
- 实付：￥4.75
- 用途：用于 AI-1811 电脑串口测试；12B 单模块测试已由 AI-1811 直接连接 STM32 完成。

## 12. 加高底板

- 购买链接：[淘宝链接](https://e.tb.cn/h.8S5kOKAqn1nUJCL?tk=cmpBgAoDCkq)
- 实付：￥25.50

## 13. 电工胶带

- 购买链接：[淘宝链接](https://e.tb.cn/h.86wFXRRA5jBgFPj?tk=WWFVgAoAXv1)
- 实付：￥7.80

## 14. 箱子

- 购买链接：[淘宝链接](https://e.tb.cn/h.8ke6nL7NpdoubeU?tk=M2gzTW9kAEQ)
- 实付：￥23.63

## 支出合计

目前共计消费：**￥822.36**。

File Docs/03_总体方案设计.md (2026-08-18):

# 03 总体方案设计

## 1. 设计目标与边界

Robot_Treasure 为四轮差速机器人，核心原则是“稳定优先”。优先保证黑线循迹、路口判断、宝藏获取和故障停车可靠，再逐步提高速度。不采用 Jetson、摄像头、YOLO 或 ROS。

系统由 STM32F103RCT6、R5 四驱机械平台、四个带编码器电机、MD240A 四路驱动、分路供电、双 NCHD12 灰度模块、已完成单模块基础读取的 AI-1811 ToF 敌方检测候选方案、普通红外备用模块、磁铁及声光提示组成；四方向多 ToF 方案仍待验证。

## 2. 硬件总体架构

```text
前 NCHD12 ─┐                         ┌─ 前/后/左/右 ToF（候选）
后 NCHD12 ─┴─ I²C ── STM32F103RCT6 ──┤
四路 AB 编码器 ───────────────────────┤
                                     └─ 状态机 / 导航 / PID
                                                │
                                  四路 PWM、方向、使能 GPIO
                                                │
                                          MD240A（TB6612FNG）
                                                │
                         Motor_FL / Motor_RL / Motor_FR / Motor_RR
```

从 11C 开始，当前车辆以前车尾重新定义为车头；已确认的物理轮位为：MD240A A→`Motor_FR`（右前）、B→`Motor_FL`（左前）、C→`Motor_RR`（右后）、D→`Motor_RL`（左后）。11D-1 已逐通道确认车辆前进的电气方向为 B/A→ELEC_REV、D/C→ELEC_FWD，原始编码器对应的逻辑符号为 B/D=+1、A/C=-1；车辆后退使用相反电气方向。11D-2 已在落地条件下确认四轮独立速度 PI 的前进直行：左侧分组 B+D、右侧分组 A+C，目标最终 80 RPM，四轮最终约 77～79 RPM，整体左右平均转速差约 0.2 RPM，未出现长期 PI 饱和；B 无固定补偿，B 最大 PWM 为 246（上限 300）。该结论仅覆盖新车头下的前进直行，不表示后退、转向或灰度循迹闭环已验证。四轮差速实现前进、后退及原地/差速转向；禁止同侧两台电机并联到同一通道。

## 3. 底盘与动力方案

### 3.1 R5 铝合金四驱底盘（已购买）

| 项目 | 参数 |
|---|---|
| 底盘 | R5 系列铝合金四驱底盘 |
| 底板 | 2 mm 铝合金 |
| 轮胎 | 65 mm 黑色大摩擦力轮胎 |
| 外形尺寸 | 约 190 mm × 198 mm × 72 mm |
| 商品标注重量 | 约 0.97 kg |
| 转向形式 | 四轮差速转向 |
| 电机数量 | 4 个 |
| 电机支架 | 37 电机支架 ×4 |
| 联轴器 | 金属联轴器 ×4 |

套餐包含铝合金底板 ×1、MC520 编码器电机 ×4、65 mm 轮胎 ×4、37 电机支架 ×4、金属联轴器 ×4、XH2.54 双头排线 ×4、XH2.54 单头排线 ×4、安装工具和固定螺丝。商品尺寸及重量须在收货后重新测量。约 0.97 kg 已包含主要机械结构，后续电池、支架和电路板应控制重量与安装高度。

### 3.2 MC520P30_12V 编码器电机 ×4（已购买）

| 参数 | 数值 |
|---|---|
| 型号/类型 | MC520P30_12V；永磁有刷直流减速电机 |
| 额定电压/减速比 | 12 V / 1:30 |
| 空载/额定转速 | 360±20 RPM / 290±20 RPM |
| 额定/堵转电流 | 0.3 A / 3 A |
| 额定/堵转扭矩 | 1.5 kg·cm / 4.5 kg·cm |
| 额定功率 | 约 4 W |
| 编码器 | AB 相正交霍尔；供电 3.3～5 V；磁环 13 线 |
| 商品标注脉冲数 | 1560 / 输出轴一圈 |
| 接口 | XH2.54 6 Pin |
| 输出轴/单个重量 | 直径 6 mm D 型偏心轴 / 约 150 g |

选用原因是它为 R5 原厂配套型号，电机、支架、联轴器、轮胎和线束尺寸均匹配，四台型号一致且自带 AB 相编码器，无须加工底盘，配套驱动的安装也方便。

搭配 65 mm 轮胎，额定理论线速度为 `290 ÷ 60 × π × 0.065 ≈ 0.99 m/s`，空载理论线速度约 `1.23 m/s`。这对稳定循迹偏快，因此不换电机，而通过最大 PWM 限制、加减速斜坡、编码器速度闭环，以及直线/弯道/路口的分级目标速度控制。初期目标速度约 0.3～0.5 m/s，稳定后再提升。

编码器计算为 `13 线 × 30 = 390`，AB 相四倍频后为 `390 × 4 = 1560`。**1560/圈为商品标注值，收到实物后应通过手动旋转输出轴一圈和 STM32 编码器计数实验进行验证。**它不得被写成未经验证的单通道脉冲数。

### 3.3 MD240A 四路驱动板（技术选型已完成）

| 参数 | 数值 |
|---|---|
| 型号/芯片 | MD240A / TB6612FNG |
| 电机通道 | 4 路独立通道 |
| VM 输入 | 6～15 V |
| 单路连续/峰值电流 | 1.2 A / 3.2 A |
| 逻辑控制电压 | 3.3～5 V |
| PWM 范围/推荐值 | 0～100 kHz / 10 kHz |
| 电机接口 | XH2.54 6 Pin |
| 尺寸/重量 | 约 68 mm × 58.7 mm / 约 26 g |
| 保护 | 过流、短路、TVS 防护 |

正常运行时，`1.2 A ÷ 0.3 A = 4`，单通道连续电流有余量；但 3 A 堵转电流已接近 3.2 A 峰值能力。MD240A 因此适合该电机的正常运行，不能容许长期堵转。软件必须具备 PWM 缓启动/缓减速、最大 PWM 限制、禁止高速直接反转、堵转检测、卡死立即停止、故障延时恢复和连续故障停车。初步规则为：PWM 超过阈值而编码器速度连续 100～300 ms 接近零时，停止对应电机并记录故障；最终阈值由实车确定。

## 4. 供电与布线

```text
3S 锂电池（LB326E，12 V 2600 mAh）
    │
    ├── 总开关 ── 保险丝 ── 动力支路 ── MD240A
    │                                      ├── Motor_FL
    │                                      ├── Motor_RL
    │                                      ├── Motor_FR
    │                                      └── Motor_RR
    └── 控制支路 ── 3A 多路 DC-DC
                         ├── 5V → STM32 开发板及 5V 传感器
                         └── 3.3V → 编码器及 3.3V 模块
```

采用 LB326E 12 V 2600 mAh 3S 锂电池、12.6 V 1.5 A 配套充电器和 3 A 多路 DC-DC；它们与底盘/驱动同属配套产品体系，基本适配已确认。到货仍须检查正负极、满电电压、DC-DC 的 3.3 V/5 V 输出、空载和负载发热、电机启动时 STM32 是否复位，以及驱动板与线缆温升。用户不购买万用表，但接入 STM32 前必须借用实验室或组员的万用表测量。

电机绝不能通过 DC-DC 供电；电池直接供给 MD240A VM。MD240A 板载 3.3 V/5 V 不作为整车主要控制电源。全部模块共地，两个稳压模块的输出不得直接并联。动力线与信号线分开走，电机线避免与灰度/编码器线长距离并行。

## 5. 灰度与敌方检测

### 5.1 NCHD12 ×2（技术选型已完成）

| 项目 | 信息 |
|---|---|
| 型号/探头 | NCHD12 / 12 路 |
| 扩展芯片 | PCA9555 |
| 灵敏度与结构 | 可调；每路独立指示灯；带遮光结构 |
| 最小适配线宽 | 商品标注约 10 mm |
| 尺寸/探头间距/重量 | 约 118.8 mm × 30 mm / 约 9 mm / 约 16.5 g |

前模块负责前进循迹和主要路口判断，后模块负责后退循迹与逃跑模式。两者可联合判断车身姿态和路口状态，但默认只允许当前运动方向的主模块进入循迹 PID，不能运行两个相互冲突的独立 PID。

两块模块共用一条 I²C 总线，并由 PCA9555 的 A0/A1/A2 焊盘设置不同地址：

```text
STM32 I²C SCL ──┬── 前 NCHD12
                └── 后 NCHD12
STM32 I²C SDA ──┬── 前 NCHD12
                └── 后 NCHD12
```

| 模块 | A2/A1/A0 | 7 位地址 |
|---|---|---:|
| 前 NCHD12 | 0/0/0 | 0x20 |
| 后 NCHD12 | 0/0/1 | 0x21 |

不需要 24 路独立 GPIO、第二组 I²C 或 I²C 多路复用器；仅当实物地址焊盘无法修改时才评估备选方案。

### 5.2 ToF 激光测距候选方案（AI-1811，单模块基础读取已验证）

当前敌方检测的候选主方案是前、后、左、右四方向 ToF 测距模块。已购买的 1 个 AI-1811 ToF 激光测距模块已完成单模块基础 UART 读取；是否再购买 3 个同型号模块并扩展到四方向，或采用 ToF 与普通红外混合方案，仍须以后续实物验证决定。普通红外模块暂时保留，作为备用和对比测试使用。本文不把“四个 ToF 已经确定使用”写成既定事实。

当前购买款式参数如下：

| 参数 | 当前记录 |
|---|---|
| 系列/工作模式 | AI-1811；主动上报模式 |
| 镜头/通信接口 | 带光学透镜；UART |
| 波特率/刷新频率 | 资料记录：9600，不可调 / 30 Hz，不可调；12B 实物验证：115200、8N1，连续稳定收到固定 8 字节帧；本阶段未做精确刷新率标定 |
| 测量距离/测量盲区 | 50～4000 mm / 50 mm |
| 标称测量误差/视场角 | ±5 mm / 约 25° |
| 供电电压/UART 信号电平 | 优先使用 3.3 V / 3.3 V |
| 波长 | 940 nm |

四个模块计划分别朝向前、后、左、右，相邻模块中心方向相差约 90°。比赛赛道没有边框和墙壁，因此采用较近的敌方报警阈值时，不需要重点考虑墙壁和边框造成的误检测。单个模块视场角约 25°，正常安装时四个方向一般不会重叠，但该布局不能形成真正的 360° 无死角检测。

初步主要使用较近的敌方检测阈值，发现敌方距离可先按约 300～500 mm 进行测试，最终值须根据小车速度、制动距离和实测结果调整。软件必须设计进入阈值和退出阈值，避免距离在临界值附近反复跳变；例如“距离小于 350 mm 判定发现，距离大于 450 mm 判定离开”只能作为软件设计示例，不是最终固定参数。

### 5.3 ToF 测试要求

12B 已完成单模块基础通信验证：`V→3.3V`、`G→GND`、`T→PA3/USART2_RX`、`R` 不接；USART2 为 115200、8N1、RX Only。实测连续稳定收到 `AA 05 FW_L FW_H DIST_L DIST_H CONF SUM`，`FW`/`DIST` 为小端，`DIST` 单位为 mm，`SUM` 为前 7 字节累加和低 8 位。以下更深入的实际效果测试仍未预先填写结果：

1. 稳定检测比赛使用的黑色 ABS 板；
2. 50 mm、100 mm、200 mm、300 mm、500 mm 和 1000 mm 距离；
3. 目标处于 0°、15°、30° 和 45° 角度；
4. 静止目标、迎面运动和横向运动；
5. 不同环境光条件下的稳定性；
6. 小于 50 mm 盲区时模块返回的数据；
7. 是否出现 0 值、最大值、无效帧或距离跳变；
8. 实际刷新率和通信稳定性；
9. 模块安装高度和俯仰角是否会导致测到地面；
10. 后续多个 ToF 同时工作时是否互相干扰。

### 5.4 AI-1811 与 STM32 连接及资源约束

电脑串口测试阶段使用 USB 转 TTL；12B 已由 AI-1811 直接连接 STM32 完成单模块基础读取。当前已验证的接线为：

| AI-1811 引脚标识 | STM32 连接 |
|---|---|
| `V` | 3.3 V |
| `G` | GND |
| `T` | PA3 / USART2_RX |
| `R` | 当前不接 |

本次单模块接线不向 AI-1811 发送命令，故 `R` 不接；不要根据连接线颜色判断引脚，必须依据模块上的 `V`、`G`、`R`、`T` 标识接线。AI-1811 为主动上报模式，会连续发送数据。PA2 保持现有电机 D 路 PWM 分配，不分配为 USART2_TX；USART3 PB10/PB11 继续作为 CH340 调试口。多个模块的发送端不能直接并联到同一个 STM32 串口 RX，否则可能出现数据帧冲突。

最终四模块通信方案暂未确定，不能提前声称四个模块能够直接接入四个独立 UART。制作 STM32F103RCT6 CubeMX 引脚分配表时，仍需验证可用硬件串口数量、UART 引脚复用、调试串口占用、DMA 和中断资源，以及是否需要串口切换、外部多路复用或其他通信方案。

## 6. 硬件关联与设计约束

1. 290 RPM 电机配 65 mm 轮胎速度偏高，必须依赖编码器闭环、PWM 限制和减速策略；惯性也要求限制电池与板卡安装高度。
2. 堵转电流接近 MD240A 峰值，软件堵转保护不可省略。
3. 3S 电池电压同时匹配 12 V 电机和 MD240A 的 6～15 V VM 输入；DC-DC 将动力与控制分支隔离，降低电机噪声导致 STM32 复位的风险。
4. NCHD12 的 I²C 接口只占 SCL/SDA 两个引脚，为四路编码器、四路 PWM 和方向控制保留了定时器/GPIO。
5. 四个独立编码器支持四轮速度补偿、卡轮识别与闭环，不因基础阶段同侧同速而失去独立输出能力。
6. 电池应靠近底盘几何中心并低位固定；MD240A 靠近电机缩短动力线；DC-DC 靠近电池输入与 STM32 供电区；STM32 放在便于接线与调试的位置。
7. 电路板使用尼龙柱、铜柱或绝缘板，不能直接接触铝合金底板。编码器/I²C/UART 线尽量短，动力线和传感器线分开；ABS 板不得遮挡灰度、ToF 镜头或红外探头。

## 7. CubeMX 资源边界

除已完成的 12A 单路基础测试接口外，本次不虚构最终整车具体引脚。后续必须验证开发板实际引出脚及复用冲突：4 路 PWM、4 个电机的方向/使能 GPIO、4 组 AB 编码器（8 输入）、一组 I²C、候选四方向 ToF 所需的 UART 接收路径、UART 调试、LED、蜂鸣器、SWDIO、SWCLK、可选电池电压 ADC、备用扩展接口，以及 TIM1～TIM4 编码器模式、PWM 定时器、MD240A 实际接口数量。12A 使用 PB14 仅代表当前基础测试接口，不代表最终整车永久分配；四个 ToF 的最终串口实现方式仍待 CubeMX 验证，普通红外是否作为混合方案的一部分也未定。

## 8. 待实物验证/待定附件

电机编码器计数、NCHD12 位序（逐路遮挡后才确定翻转规则）、灰度支架高度、AI-1811 ToF 测试结果、ToF 最终数量和多模块通信方式、普通红外是否混合使用、总开关、保险丝、连接器、动力/信号线规格、MOSFET 或三极管、强力磁铁和各类支架仍需落实。电池、驱动板和 DC-DC 必须牢固固定，黑色 ABS 板不得遮挡传感器。

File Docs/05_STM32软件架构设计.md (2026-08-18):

# 05 STM32 软件架构设计

本文描述与当前硬件基线对应的软件边界和接口规划，不在本次文档中虚构 STM32F103RCT6 的具体引脚分配。

## 1. 分层结构

```text
main.c
  └─ Control：RobotState / Strategy / FaultManagement
       └─ Algorithm：GrayPosition / SpeedPID / TrackPID / IntersectionDetection / Navigation
            └─ Hardware：Motor / Encoder / MD240A / NCHD12 / ToF / Infrared（备用/对比） / Power / Buzzer_LED
                 └─ STM32 HAL、定时器、I²C、GPIO、UART
```

| 层 | 模块 | 职责 |
|---|---|---|
| Hardware | `Motor`、`MD240A` | 四个独立 PWM、方向与使能输出；执行斜坡、反转保护和停机 |
| Hardware | `Encoder` | 四组 AB 相计数、速度计算、零速/堵转观察 |
| Hardware | `NCHD12` | PCA9555 配置、双模块读取、位序归一化、超时与错误状态 |
| Hardware | `ToF` | 候选 ToF 模块的 UART 接收、数据帧解析、距离有效性、超时和方向距离接口 |
| Hardware | `Infrared`、`Power`、`Buzzer_LED` | 普通红外备用/对比采集、可选电池 ADC、声光输出 |
| Algorithm | `GrayPosition`、`TrackPID` | 根据当前主灰度模块计算横向误差、线宽和路口特征 |
| Algorithm | `SpeedPID`、`IntersectionDetection`、`Navigation` | 四轮闭环、路口识别与路径动作 |
| Control | `RobotState`、`Strategy`、`FaultManagement` | 模式选择、比赛策略、故障降速/恢复/停车 |

## 2. 控制链路与周期

```text
前部或后部灰度模块
  ↓ 横向误差、线宽、路口特征
循迹外环
  ↓ 左右侧目标速度
四轮目标速度分配
  ↓ 四轮编码器速度 PID
MD240A 四路 PWM、方向、使能
```

基础阶段可让同侧前后轮使用相同目标速度，但四个独立反馈和独立输出能力必须保留。前进时以前 NCHD12 为主，后退时以后 NCHD12 为主；可用另一模块作为状态判断辅助，但绝不同时运行两个互相冲突的循迹 PID。

推荐基础控制周期为 10 ms（100 Hz）：

1. 读取前 NCHD12；
2. 读取后 NCHD12；
3. 检查有效性和时间戳；
4. 计算灰度位置误差；
5. 读取编码器速度；
6. 执行状态机和 PID；
7. 更新四轮目标速度；
8. 更新 MD240A 输出。

单块 I²C 读取约 0.2～0.5 ms，两块顺序读取约 0.4～1 ms，I²C 带宽不是瓶颈。初期通信测试用 50 Hz，基础循迹 100 Hz，高速和路口测试可提高到 100～200 Hz。

## 3. NCHD12 / PCA9555 驱动规范

两块 NCHD12 共用一条 I²C 总线，驱动层仅保存 7 位地址：

```c
#define NCHD12_FRONT_ADDR  0x20U
#define NCHD12_REAR_ADDR   0x21U
```

HAL 的 `DevAddress` 使用 `addr7 << 1`。`0x20` 是 7 位地址；`0x40` 和 `0x41` 分别是默认 8 位写/读地址表示，绝不能混用。

初始化显式写入 PCA9555：Configuration Port 0（`0x06`）=`0xFF`、Configuration Port 1（`0x07`）=`0xFF`、Polarity Port 0（`0x04`）=`0x00`、Polarity Port 1（`0x05`）=`0x00`。读取从 Input Port 0（`0x00`）连续取两字节：

```c
uint16_t raw = ((uint16_t)high_byte << 8) | low_byte;
uint16_t sensor_bits = raw & 0x0FFF;
```

bit0～bit11 对应 12 路灰度；低字节是前 8 路，高字节低 4 位为余下 4 路，高字节高 4 位未用。该接口没有 CRC、长度字段或私有数据帧。

```c
typedef struct
{
    uint16_t front_bits;
    uint16_t rear_bits;
    uint32_t front_timestamp_ms;
    uint32_t rear_timestamp_ms;
    uint8_t front_valid;
    uint8_t rear_valid;
} GraySensorData;
```

上层物理方向统一为 bit0=车辆左侧最外探头、bit11=右侧最外探头。前后安装方向可能不同，须由 `NCHD12_NormalizeFront()` 和 `NCHD12_NormalizeRear()` 分别处理；实际反转规则等待逐路遮挡实测后确定，不能预先写死。

建议接口为：`NCHD12_Init()`、`NCHD12_Read(addr7, bits)`、`NCHD12_ReadFront()`、`NCHD12_ReadRear()`、`NCHD12_NormalizeFront()`、`NCHD12_NormalizeRear()`、`GraySensor_Update()`、`GraySensor_CheckTimeout()`。

读取失败不得伪装成合法全 0。除结构体状态外应保存 `front_error_count`、`rear_error_count`、`front_last_update`、`rear_last_update`，并处理 I²C NACK、总线卡死、数据不更新、长期全 0/全 1、脱线及主循迹模块失效。前进时前模块、后退时后模块连续失效，必须降速或停车，不得沿用旧数据高速行驶。

## 4. ToF 传感器驱动规划

在 `Hardware/` 层增加候选模块驱动文件：

```text
Hardware/
├── tof_sensor.c
└── tof_sensor.h
```

整车 ToF 驱动仍仅规划架构和接口，不创建未经验证的完整驱动代码；12B 单模块测试工程已实现正式帧解析，并由模块直接连接 STM32 完成基础读取。资料记录的波特率为 9600（不可调），但 12B 实物验证使用并确认 115200、8N1；主动上报、30 Hz 刷新频率、50～4000 mm 测量距离、50 mm 盲区和约 25° 视场角仍按资料记录，其中刷新率和精度未在本阶段精确标定。供电使用 3.3 V，UART 信号为本次实测接收配置。

12B 单模块连接约定为：`V → STM32 3.3V`、`G → STM32 GND`、`T → PA3 / USART2_RX`、`R` 不接。USART2 为 115200、8N1、RX Only，PA2 不分配为 USART2_TX；USART3 PB10/PB11 保持 CH340 调试口。接线依据模块 `V/G/R/T` 标识，不依据线色。主动上报模式会连续发送数据；多个模块的发送端不能直接并联到同一个 STM32 UART_RX。

建议先规划以下接口：

```c
ToF_Init()
ToF_Update()
ToF_ParseFrame()
ToF_GetDistance()
ToF_IsValid()
ToF_IsEnemyDetected()
```

驱动应覆盖：

- UART 数据接收及接收时间戳；
- 数据帧边界、长度/校验等格式解析（具体帧格式须以实物资料和串口测试确认，不能预先臆造）；
- 距离有效性检查、50 mm 盲区处理、0 值/最大值/无效帧处理；
- 接收超时和连续无效数据处理；
- 距离滤波、连续多帧确认、进入/退出阈值迟滞，避免临界值附近反复跳变；
- 前、后、左、右方向距离的统一获取接口。

敌方检测不应只依据单次距离。候选四方向方案的最终数量、UART 数量和通信拓扑仍需在 CubeMX 中验证可用硬件串口、UART 引脚复用、调试串口占用、DMA/中断资源，并评估串口切换、外部多路复用或其他方案；不能提前声称四个模块已能直接接入四个独立 UART。后续多个 ToF 同时工作时的互相干扰也必须通过实测确认。

## 5. 电机、编码器与故障管理

当前物理轮位基线为 MD240A A→`Motor_FR`、B→`Motor_FL`、C→`Motor_RR`、D→`Motor_RL`。11D-1 已验证车辆前进时 A/B 使用 ELEC_REV、C/D 使用 ELEC_FWD，编码器逻辑符号 A/C=-1、B/D=+1；车辆后退使用相反电气方向。11D-2 已验证前进直行使用四个独立速度 PI，左侧分组为 B+D、右侧分组为 A+C；Kp=0.80、Ki=0.25、目标最终 80 RPM、每 100 ms 增加 4 RPM、PWM 上限 300、最长运行 3 秒。B 不使用固定 PWM 补偿，所需输出由其独立 PI 调节。该结论仅覆盖前进直行；后退、转向和循迹控制仍待独立阶段实现与验证。推荐 PWM 为 10 kHz。初期目标车速约 0.3～0.5 m/s，使用最大 PWM、加减速斜坡和速度 PID 避免 290 RPM 配 65 mm 轮胎带来的过快响应。

单电机堵转电流 3 A 接近驱动板 3.2 A 峰值，故障层必须在 PWM 超阈值且编码器速度连续 100～300 ms 接近零时停止相应电机、记录故障、延时恢复；连续故障转入停车状态。禁止高速直接反转。

## 6. CubeMX 资源需求

| 功能 | 资源要求 |
|---|---|
| 四个电机 | 4 路 PWM；方向、使能等 GPIO；MD240A 实际接口数量核对 |
| 四个编码器 | 4 组 AB 相，共 8 路输入；验证 TIM1～TIM4 编码器模式 |
| 双 NCHD12 | 一组 I²C（SCL/SDA） |
| 候选 ToF | 至少验证 1 路 UART 接收；四模块最终通信路径未定，需检查可用硬件串口、UART 引脚复用、DMA/中断资源 |
| 备用红外 | 12A 基础测试暂用 PB14；是否保留为混合方案的一部分及最终永久 GPIO 分配仍待决定 |
| 外围 | LED 输出、蜂鸣器输出、UART 调试、可选电池 ADC、备用扩展 |
| 调试 | SWDIO、SWCLK，且核对开发板实际引出脚 |

必须在 CubeMX 中完成 PWM 定时器、TIM1～TIM4 编码器模式、引脚复用冲突、I²C、UART、SWD、开发板实际引脚和 MD240A 实际接口数量的联合验证。具体引脚分配等待该验证完成后确定。

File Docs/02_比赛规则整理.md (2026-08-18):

# 密室夺宝比赛规则整理

> 本文面向 Robot_Treasure 机器人的机械、电控和软件研发，用于快速定位比赛约束并指导方案设计。规则内容依据《2025 江苏省大学生机器人大赛密室夺宝项目竞赛规则 V2.0》提炼；项目最终参赛要求应以组委会最新发布的正式规则、补充通知及现场说明为准。

## 1. 项目简介

本项目对应 **2025 江苏省大学生机器人大赛“密室夺宝”项目**。比赛由两台自主机器人进行对抗，双方角色分别为：

- **警方机器人**：寻找并保护宝藏；如果宝藏已被小偷获取，则实施抓捕。
- **小偷机器人**：争取先于警方获取宝藏，并携带宝藏逃脱警方抓捕。

因此，机器人不仅需要完成迷宫循迹和宝藏获取，还需要根据本方角色、宝藏状态及对手机器人的位置执行不同策略。

## 2. 比赛任务

单局比赛的核心任务链如下：

```text
开始比赛
    ↓
机器人自主运行
    ↓
寻找宝藏区域
    ↓
获取宝藏
    ↓
持续触发声光提示
    ↓
警方完成抓捕 / 小偷保持未被抓捕直至比赛结束
```

研发时可将任务拆分为六个状态：启动、循迹导航、宝藏区搜索、宝藏获取确认、声光提示、抓捕或逃脱。声光提示必须由“确认已获取宝藏”这一条件触发，不能仅凭机器人进入宝藏区触发。

## 3. 比赛流程

| 阶段 | 规则要求 | 研发关注点 |
|---|---|---|
| 赛制 | 三局两胜制 | 至少赢得两局才能赢得整场比赛 |
| 角色 | 双方角色轮换 | 同一机器人应支持警方与小偷两套策略，或支持赛前切换角色配置 |
| 单局开始 | 机器人按比赛要求启动后自主运行 | 启动后不得依赖遥控或人工干预 |
| 单局进行 | 每局限时 3 分钟 | 导航、取宝及对抗策略必须在时间限制内完成 |
| 单局结束 | 根据宝藏获取、抓捕和超时状态判定胜负 | 软件应可靠保存“是否取宝”和“当前角色”等关键状态 |

## 4. 场地规则

| 项目 | 要求 |
|---|---|
| 场地尺寸 | 3.6 m × 3 m |
| 车道宽度 | 0.3 m |
| 黑线宽度 | 25 mm |
| 比赛地图 | 迷宫地图 |
| 宝藏位置 | 宝藏区中心 |

工程上，机器人应围绕 25 mm 黑线完成循迹与路口识别；底盘外形和转弯能力需要适应 0.3 m 宽车道。宝藏获取机构应能在机器人到达宝藏区中心附近时可靠工作。

## 5. 宝藏获取规则

- 宝藏为**铁块**，获取机构必须能够可靠吸附、夹持或承载该物体。
- 机器人必须具备**宝藏检测功能**，不能只用固定延时推定获取成功。
- 机器人确认获取宝藏后，必须持续进行**声、光提示**。
- 未获取宝藏时禁止提前发出代表取宝成功的声光提示。

对应的软件触发关系应为：

```text
获取机构动作 → 宝藏传感器确认 → 锁存“已获取”状态 → 持续开启 LED 和蜂鸣器
```

传感器未确认时，不应进入“已获取”状态。具体检测传感器及阈值需要通过实物铁块测试确定。

## 6. 胜负判定

### 6.1 警方胜利

- 警方先获取宝藏；或
- 小偷已携带宝藏时，警方完成对小偷的抓捕。

### 6.2 小偷胜利

- 小偷获取宝藏；并且
- 在本局比赛时间内未被警方抓捕。

### 6.3 平局

- 比赛结束时双方均未获取宝藏。

工程实现中，角色不同会改变取宝后的目标：警方取宝后以保护宝藏为主；小偷取宝后则需要在余下时间内持续规避警方。

## 7. 机器人设计限制

| 规则 | 设计影响 |
|---|---|
| 尺寸限制 ≤ 0.28 m³ | 限制底盘及全部安装结构的总体空间，设计完成后需按官方检录口径复核 |
| 必须自主运行 | 不能遥控；启动、导航、取宝、提示及对抗决策均需在机器人端完成 |
| 沿黑线循迹 | 需要灰度传感器，并针对 25 mm 黑线完成安装间距、阈值及控制参数标定 |
| 获取铁块宝藏 | 需要取宝机械结构，同时需要检测宝藏是否真正获取 |
| 获取后持续声光提示 | 需要 LED、蜂鸣器及可锁存的取宝状态逻辑 |
| 安装机器人识别结构 | 需要预留识别板的安装位置，保证结构稳固且符合规则要求 |
| 车道宽度 0.3 m | 底盘宽度、转弯轨迹和外伸机构应避免超出可行驶空间 |
| 单局限时 3 分钟 | 路径规划、行驶速度和异常恢复策略需要满足时间约束 |

> “设计影响”是从规则推导出的工程要求，不是新增竞赛规则。尺寸和识别结构应在制作、检录前再次对照当届正式文件确认测量方式及安装细节。

## 8. 当前 Robot_Treasure 方案对应

| 规则要求 | 当前对应设计 | 状态与验证重点 |
|---|---|---|
| 25 mm 黑线循迹 | 12 路灰度传感器 + 循迹 PID | 已确定方案；需在正式赛道材质上标定阈值和安装高度 |
| 迷宫导航 | 路口识别 + 路线判断 | 软件框架已规划；需覆盖岔路、丢线和转弯恢复 |
| 获取铁块宝藏 | 磁吸机构 | 已确定方案；需验证吸力、对位容差及行驶中防脱落能力 |
| 必须检测宝藏 | 宝藏检测功能待选型 | 规则要求已明确；当前方案仅描述延时吸取，需补充独立的获取确认手段 |
| 获取后持续声光提示 | 高亮 LED + 蜂鸣器 | 已确定方案；应由宝藏检测结果触发并保持至本局结束 |
| 自主运行 | STM32 主控 + 机器人状态机 | 已确定总体方向；需实现警方/小偷角色配置及全过程自主控制 |
| 对手机器人检测 | 前、后、左、右四方向 ToF 测距候选方案（1 个 AI-1811 已完成单模块基础 UART 读取；普通红外备用/对比） | 项目方案仍需选型；黑色 ABS 检测、距离/角度、运动目标、环境光及多模块通信尚未完成验证，再决定是否扩展到四方向 |
| 适应尺寸及车道限制 | 四轮普通轮差速底盘 | 已确定方案；结构定型后需实测外形、转弯包络和 0.3 m 车道通过性 |
| 机器人识别结构 | 预留识别板安装位 | 尚未在现有总体方案中落实，机械设计阶段需补充 |

上述传感器、机构和底盘是 **Robot_Treasure 当前工程方案**，并非官方规则指定的唯一实现方式。

## 9. 参考来源

- 《2025 江苏省大学生机器人大赛密室夺宝项目竞赛规则 V2.0》：本文比赛任务、场地参数、宝藏规则、胜负判定及机器人限制的主要依据。
- 《2026 江苏省大学生机器人大赛通知》：用于确认后续参赛安排及当届文件要求；若其附件发布新版专项规则，应以新版规则为准。
- [`Docs/03_总体方案设计.md`](03_总体方案设计.md)：Robot_Treasure 的主控、传感器、底盘、取宝及提示方案来源。
- [`Docs/04_硬件清单.md`](04_硬件清单.md)：当前器件规划和待确认事项来源。

> 版本说明：本文不收录报名、申诉、裁判组织等与机器人研发无直接关系的流程。若官方文件更新，应优先复核场地尺寸、机器人尺寸、宝藏规格、抓捕条件、识别板要求和胜负判定。

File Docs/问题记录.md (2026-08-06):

# 问题记录

本文件仅记录项目中已实际观察到的问题、已做检查和处理结论。原因判断中的“可能原因”不等同于已确认事实。

## 问题编号：P001

### 所属阶段

Motor_A_PwmRpm_Test、Four_Motor_SpeedPid_Test（10E）和 Four_Motor_GroundStraight_Test（10F）。

### 问题现象

B 电机在相同开环 PWM 下的转速较慢。

### 排查过程

已进行同 PWM 转速对比；随后对 B 编码器进行人工计数标定，结果约为 1565.1 count/rev。

### 原因判断

- 已确认原因：B 编码器计数与统一值 1560 的差异约 0.3%，不足以解释明显偏慢。
- 可能原因：电机个体差异、传动阻力或地面负载差异。
- 尚未确认：具体占主导的机械或电气因素。

### 解决方法

四轮速度 PI 分别使用独立反馈和独立输出调节；未给 B 写入固定额外 PWM 补偿。

### 当前状态

持续观察。

### 后续注意

不得以“其他轮 PWM 加固定值”的方式补偿 B；应继续依据单轮反馈闭环判断。

## 问题编号：P002

### 所属阶段

Four_Motor_Base、Four_Motor_SpeedPid_Test（10E）。

### 问题现象

B 编码器人工标定约为 1565.1 count/rev，而四轮工程统一使用 1560 count/rev。

### 排查过程

将人工标定值与统一计数比较，差异约 0.3%。

### 原因判断

- 已确认原因：该差异较小，不是 B 电机明显偏慢的主要原因。
- 可能原因：人工标定存在正常测量误差。
- 尚未确认：是否存在更长期的计数偏差。

### 解决方法

当前四轮仍统一使用 1560 count/rev，不单独修改 B 的计数参数。

### 当前状态

暂时接受。

### 后续注意

若重新标定，应记录测试条件；在有充分证据前不得单独改动 B 的每圈计数。

## 问题编号：P003

### 所属阶段

Four_Motor_SpeedPid_Test（10E）。

### 问题现象

四轮停止后，单轮数据已显示为停止状态，但左右平均速度仍保留停止前的值，串口报告互相矛盾。

### 排查过程

检查发现停止后 PI 结构体被复位，而 Chassis 平均值仍来自未刷新缓存；随后核对每个控制周期的反馈调用链。

### 原因判断

- 已确认原因：单轮显示与左右平均值使用了不同来源、不同时间帧的反馈数据。
- 可能原因：无。
- 尚未确认：无。

### 解决方法

停止、禁用和运行状态均以固定周期调用 `Chassis_UpdateFeedback()`；串口单轮 measured 与左右平均值统一来自同一 Chassis 反馈帧，停止状态不执行 PI 输出。

### 当前状态

已解决。

### 后续注意

同一周期内每路 `Encoder_GetDelta()` 只能读取一次；显示层不得用已清零的 PI measured 替代 Chassis 反馈。

## 问题编号：P004

### 所属阶段

Four_Motor_SpeedPid_Test（10E）、Four_Motor_GroundStraight_Test（10F）。

### 问题现象

紧急停止后的第一帧可能仍显示惯性转速，下一帧回到零。

### 排查过程

停止和禁用状态下继续按固定周期读取编码器反馈，观察到该现象发生在 PWM 已归零之后。

### 原因判断

- 已确认原因：机械惯性会在停止后的首个反馈周期留下实际转动数据。
- 可能原因：无。
- 尚未确认：无。

### 解决方法

保留真实反馈，不为显示目的伪造零值；PWM、目标和 PI 积分仍立即清零。

### 当前状态

暂时接受。

### 后续注意

分析停机日志时应区分 PWM 命令已归零与机械速度完全归零两个时刻。

## 问题编号：P005

### 所属阶段

Four_Motor_GroundStraight_Test（10F）。

### 问题现象

80 RPM 落地直行约 50 cm 时向右偏约 2～3 cm；后退轨迹大致返回起点。

### 排查过程

已完成前进、后退落地观察：未见原地旋转、单轮反转或明显失控。

### 原因判断

- 已确认原因：当前表现为稳定的轻微偏差。
- 可能原因：左右轮负载、摩擦或速度细小差异。
- 尚未确认：偏差的唯一物理来源。

### 解决方法

当前不增加 B 轮固定 PWM 补偿，也不增加左右固定速度补偿；后续以灰度传感器动态纠偏处理。

### 当前状态

持续观察。

### 后续注意

不得把稳定轻微偏差直接归因于某一个车轮，或在缺少数据时加入固定补偿。

## 问题编号：P006

### 所属阶段

STM32 脱线测试供电。

### 问题现象

脱线测试时需要明确 STM32 的供电路径，避免把驱动板输入端作为 STM32 供电端。

### 排查过程

已确认脱线测试供电使用驱动板 VOUT 5V。

### 原因判断

- 已确认原因：STM32 脱线测试的指定供电路径为驱动板 VOUT 5V。
- 可能原因：无。
- 尚未确认：无。

### 解决方法

STM32 使用驱动板 VOUT 5V 供电；不得将驱动板 VIN 直接接入 STM32。

### 当前状态

已解决。

### 后续注意

每次脱线测试前均应复核供电端子名称和极性；不得凭名称猜测电源连接。

## 问题编号：P007

### 所属阶段

11A｜12路灰度传感器 I2C 基础读取与通道映射验证（`Gray12_I2C_BasicRead_Test`）。

### 问题现象

I2C 地址扫描能够发现设备，但曾出现“设备已发现，PCA9555-compatible 寄存器读取失败”的提示。

### 排查过程

- 检查供电、共地、SCL 和 SDA 连接。
- 完整断电后重新上电复测。
- 保留 RAW16 串口输出和 I2C 错误提示，便于区分地址应答与寄存器读写失败。
- 将 I2C 地址、寄存器访问、原始数据读取和错误状态集中到 `Hardware/NCHD12`。
- 最终硬件复测正常，未持续出现读取失败。

### 原因判断

- 已确认原因：当时设备地址能够应答，但寄存器读写失败。
- 可能原因：接线状态、热插拔或上电状态可能影响当次通信。
- 尚未确认：导致该次读取失败的唯一根本原因。

### 解决方法

完成断电重上电和连接检查；驱动保留 RAW16 与 I2C 错误提示，并将 PCA9555-compatible 访问集中到 `Hardware/NCHD12`。最终测试已正常通过。

### 当前状态

已解决

### 后续注意

禁止带电插拔 I2C 线和供电线。若再次发生，先记录地址扫描结果、RAW16 和错误提示，再检查接线与上电过程；不得将可能原因写为已确认原因。

## 问题编号：P008

### 所属阶段

11B｜12路灰度位置与横向误差计算（`Gray12_Position_Test`）。

### 问题现象

第一版 `Gray12_Position_Test` 静态检查通过、Keil 编译完成后，下载时报错：`Error: Flash Download failed - "Cortex-M3"`。相同硬件和 11A 工程此前能够正常下载。

### 排查过程

- 删除尚未提交的第一版 `Gray12_Position_Test`。
- 从可正常下载的 `Gray12_I2C_BasicRead_Test` 完整复制工程，连同 `.uvprojx`、`.uvoptx` 及 Keil 辅助配置一起保留。
- 保留 Device、ROM/RAM、ST-Link、SWD、Reset、Utilities 和 Flash Algorithm 设置；在完整复制工程上仅改项目名称、输出名称、App 引用和 11B 所需源码登记。
- 重新加入 GrayPosition 与 App 代码后，Keil 编译和硬件下载均正常。

### 原因判断

- 已确认原因：第一版新工程没有可靠继承完整可用的 Keil 工程配置。
- 尚未确认：究竟是哪一个单独配置项导致下载失败。
- 不将某一个 Flash Algorithm、ST-Link 选项或 `.uvoptx` 文件表述为唯一确定根因。

### 解决方法

通过完整继承 11A 已验证工程的配置解决下载问题。

### 当前状态

已解决。

### 后续注意

- 相同硬件的新测试工程优先完整复制最近已验证工程，且必须连同 `.uvprojx` 和 `.uvoptx` 一起复制。
- 不从零重建 Keil XML，不随意删除不了解的下载配置。
- 修改后比较 Device、Debug、Utilities、Flash 和 SWD 设置；新工程第一次提交前必须完成编译和下载验证。

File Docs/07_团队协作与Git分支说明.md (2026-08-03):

# Robot_Treasure 团队协作与 Git 分支使用说明

本文是 [00_Git使用说明.md](00_Git使用说明.md) 的补充，面向多人同时开发同一项目的情况。重点是：每个人在自己的功能分支上完成一项任务，再通过 Pull Request（PR）合并到稳定的 `main` 分支。

## 1. 分支是什么

Git 分支是代码的独立开发线，不是聊天分组。

- `main`：稳定分支，只保留已经检查或测试过、可以供全组使用的内容。
- 功能分支：为一个具体模块或任务创建的临时开发线，完成并合并后可以删除。
- 一个分支只处理一项任务，分支名使用功能名称，不使用个人姓名。

本项目可使用下列命名方式：

```text
feature/motor-md240a
feature/gray-nchd12
feature/tof-ai1811
feature/encoder-mc520
```

## 2. 开始一项任务

每次开始新任务前，先回到 `main` 并获取团队最新代码，然后创建自己的功能分支。

```powershell
cd F:\Robot_Treasure
git switch main
git pull origin main
git switch -c feature/gray-nchd12
git branch
```

命令说明：

- `cd F:\Robot_Treasure`：进入项目根目录。
- `git switch main`：切换到稳定分支。
- `git pull origin main`：从 GitHub 获取并合并远程 `main` 的最新内容。
- `git switch -c feature/gray-nchd12`：创建并立即切换到灰度模块功能分支。实际使用时请替换为自己的任务名。
- `git branch`：查看本地分支；前面带 `*` 的分支就是当前所在分支。

创建分支前先确认工作区没有与本任务无关的修改。若已有未提交内容，先与负责人确认其归属，不要直接带入新任务。

## 3. 开发与提交流程

完成一个可以检查的小阶段后，使用下面的流程提交到本地仓库：

```powershell
git status
git add .
git status
git commit -m "完成NCHD12灰度模块基础读取"
```

命令说明：

- 第一次 `git status`：查看哪些文件被修改、新增或删除。
- `git add .`：将当前目录下的修改加入暂存区。只有在确认列出的文件都属于本次任务时才使用它；不确定时，改用 `git add 路径\文件名` 精确暂存。
- 第二次 `git status`：确认“准备提交的更改”只包含本次任务内容。
- `git commit -m "..."`：把暂存区内容保存为一条本地提交记录。

提交信息不要写成“修改”“更新”等模糊文字，应说明完成或修正了什么。例如：

```text
完成PCA9555基础读取
完成AI-1811串口数据解析
修正MD240A右后电机方向
补充MC520编码器测试记录
```

建议每完成一个可编译、可检查或可测试的阶段就提交一次。不要把多项无关工作堆到同一条提交中。

## 4. 首次推送功能分支

新建分支第一次推送时执行：

```powershell
git push -u origin feature/gray-nchd12
```

其中 `-u` 用于建立本地分支与远程同名分支的关联。设置后，后续在该分支上完成提交只需执行：

```powershell
git push
```

推送前再次执行 `git status`，确认没有把临时文件、无关资料或其他成员的工作带入本次推送。

## 5. 多人协作注意事项

1. `main` 只保存已检查或测试过的稳定内容。
2. 开始任务前必须从最新 `main` 创建功能分支。
3. 不要直接在 `main` 上开发。
4. 一个分支只处理一项任务。
5. 优先只修改自己负责的模块。
6. 必须修改其他成员模块前，先沟通并说明修改范围。
7. 不要随意删除、移动或批量重命名文件。
8. 商家示例代码只能作为参考；使用前要确认其适用型号和接口，不能直接当作项目正式代码。
9. 每次提交应对应一个可验证阶段，并写清楚提交信息。
10. 每次 `git push` 前都先检查 `git status`。
11. 不提交编译缓存、临时文件、无关大文件、商家安装程序或宣传资料。
12. 发生冲突时先联系负责人确认，不要盲目选择“全部保留”或“全部接受”。

以下文件容易被多人同时修改，发生冲突的风险较高：

```text
*.ioc
main.c
gpio.c
tim.c
usart.c
stm32f1xx_it.c
Keil 工程文件
```

当前团队约定：CubeMX 引脚、定时器、`.ioc` 文件和 Keil 主工程配置由指定集成人员维护。其他成员如需改动这些共享配置，必须提前沟通并由集成人员确认后处理。

## 6. Pull Request 使用方法

Pull Request（PR）是把功能分支申请合并到 `main` 的页面记录。创建 PR 不等于已经合并；它的作用是让负责人和队友查看修改文件、提交记录和测试情况，再决定是否合并。

当前仓库尚未设置 `main` 的强制保护规则，因此更需要依靠团队约定：不要自行合并自己的 PR，必须等待负责人审核和合并。

### 网页创建 PR 的步骤

1. 完成功能分支上的一个可检查阶段。
2. 执行 `git push`，将本地功能分支推送到 GitHub。
3. 在浏览器打开本项目 GitHub 仓库。
4. 点击页面出现的 **Compare & pull request**。
5. 确认 `base` 为 `main`，`compare` 为自己的功能分支。
6. 填写清晰的 PR 标题。
7. 在描述中写明完成内容、修改文件和测试结果。
8. 点击 **Create pull request**。
9. 将 PR 链接或分支名称发给负责人。
10. 等待负责人审核、提出修改意见或合并。

PR 标题示例：

```text
完成NCHD12灰度模块基础读取
完成AI-1811串口数据解析
修正MD240A右后电机方向
```

PR 描述可直接使用下面模板：

```markdown
## 本次完成
- 

## 修改文件
- 

## 测试结果
- Keil编译：
- 实物测试：
- 其他测试：

## 尚未解决
- 

## 注意事项
- 
```

### 负责人合并 PR 的步骤

1. 打开对应 PR。
2. 查看 **Files changed**，确认没有影响其他模块。
3. 查看提交说明和测试结果是否完整、可复核。
4. 有问题时要求提交者在原分支修改后再次推送。
5. 确认无误后点击 **Merge pull request**。
6. 确认合并操作，并通知全组更新 `main`。

其他成员收到通知后执行：

```powershell
git switch main
git pull origin main
```

## 7. 不要这样做

- 不要直接在 `main` 分支开发。
- 不要把未经检查或测试的内容直接推送到 `main`。
- 不要自行合并自己的 PR。
- 不要随意修改 CubeMX 共享配置、`.ioc`、定时器和 Keil 主工程配置。
- 不要在一次提交中混入大量无关修改。
- 不要使用“更新”“修改一下”等模糊提交信息。
- 不要提交商家压缩包、视频、EXE 程序、临时文件或编译产物。
- 不要在冲突发生时不看内容就覆盖其他人的修改。

## 8. 每日协作检查清单

开始开发前：确认当前分支、执行 `git pull origin main` 获取最新稳定代码。

提交前：执行两次 `git status`，确认暂存区只包含本次任务。

推送后：创建 PR，填写测试结果，并等待负责人审核合并。

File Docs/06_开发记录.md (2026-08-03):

# 06 开发记录

## 记录模板

| 日期 | 阶段/模块 | 完成内容 | 问题 | 下一步 | 负责人 |
|---|---|---|---|---|---|
| YYYY-MM-DD | — | — | — | — | — |

## 版本记录

| 版本 | 日期 | 主要变化 |
|---|---|---|
| v0.1.0 | YYYY-MM-DD | 创建项目工程骨架 |
| v0.2.0 | 2026-08-03 | 固化 R5 配套四轮独立驱动、分路供电、双 NCHD12 共用 I²C 的硬件方案 |

## 2026-08-02 硬件方案修正（历史记录，已被后续方案替代）

- 当时确认已购买 R5 系列铝合金 520 编码器电机四驱底盘和前后黑色 ABS 板，但尚未获得完整配套电机资料。
- 当时的 JGB37-520B、178RPM 方案已放弃，不是当前电机方案。
- 当时的 DRV8876 ×4 最终驱动设想已放弃，不是当前驱动方案。
- 当时有关电机、驱动和电源待确认的内容，均已由 2026-08-03 的 MC520P30_12V、MD240A、LB326E 及 3 A 多路 DC-DC 方案替代。

## 2026-08-03 硬件方案确认

- 确认 R5 底盘配套电机为 MC520P30_12V 永磁有刷编码器减速电机 ×4，额定 12 V、1:30、额定 290±20 RPM、额定 0.3 A、堵转 3 A，带 AB 相正交霍尔编码器。
- 记录编码器计算：13 线 × 30 = 390；AB 相四倍频后为 1560。1560/圈为商品标注值，待收到实物后用手动转一圈和 STM32 计数实验验证。
- 确定 MD240A 四路 TB6612FNG 电机驱动方案：四个通道分别连接左前、左后、右前、右后电机；不采用并联电机方案。
- 明确单电机堵转电流接近 MD240A 峰值能力，软件必须实现 PWM 斜坡、最大 PWM、禁止高速反转、编码器堵转检测、停机、延时恢复和连续故障停车。
- 确定 LB326E 12 V 2600 mAh 3S 锂电池及 12.6 V 1.5 A 配套充电器。
- 确定 3 A 多路 DC-DC 供电方案，建立电池经总开关和保险丝后的动力/控制分路：电池直接给 MD240A 动力端，DC-DC 给 5 V 控制支路及 3.3 V 模块；所有模块共地。
- 确定 NCHD12 12 路灰度传感器 ×2，采用 PCA9555 I²C 扩展；灰度模块不再占用 24 路 GPIO。
- 确认两块 NCHD12 使用同一条 I²C 总线：前模块 7 位地址为 0x20，后模块为 0x21；HAL 调用使用 `addr7 << 1`。
- 记录 PCA9555 数据读取方式：配置两个 Configuration Port 为输入、Polarity Port 不反相；从 Input Port 0 连续读两字节，低 12 位为灰度状态。
- 明确前灰度负责前进循迹与主要路口判断，后灰度负责后退和逃跑模式；两者不运行相互冲突的独立循迹 PID。
- 普通红外模块保留其历史采购记录，当前作为备用和对比测试使用，不再作为敌方检测的最终首选方案。
- 下一步进行 STM32F103RCT6 CubeMX 资源规划，验证四路 PWM、四组 AB 编码器、I²C、候选 ToF UART、调试 UART、SWD 以及实际引脚复用冲突。

## 2026-08-03 敌方检测方案调整

- 敌方检测方案由普通红外调整为 ToF 激光测距候选主方案，计划评估前、后、左、右四方向检测；四个 ToF 尚未确定使用。
- 已购买 1 个 AI-1811 ToF 激光测距模块（主动上报、带光学透镜）用于实际测试，并购买 1 个 USB 转 TTL 模块用于电脑串口测试。
- USB 转 TTL 仅用于模块到货后的电脑串口测试，最终装车时由 ToF 模块直接连接 STM32；测试内容包括黑色 ABS 板、距离、角度、运动目标、环境光、盲区、异常数据、刷新率、安装姿态和多模块干扰。
- 测试通过后再决定是否购买其余 3 个同型号模块并扩展到四方向，或采用 ToF 与普通红外混合方案。
- 普通红外暂时保留作为备用和对比测试，不删除其历史采购信息；当前不记录任何尚未完成的 ToF 测试结果。

## 到货/装车验收待办

- 借用万用表检查电池极性和满电电压，测量 DC-DC 的 3.3 V 与 5 V 输出后再接 STM32。
- 检查空载和负载温升、电机启动时 STM32 是否复位、MD240A 和线缆是否异常发热。
- 手动验证四个编码器计数方向和每输出轴一圈计数。
- 逐路遮挡前后 NCHD12，确定各自位序归一化规则与安装高度。
- 复测底盘商品尺寸/重量，确认电池、驱动板、DC-DC 与传感器支架的位置及 ABS 板不遮挡探头。

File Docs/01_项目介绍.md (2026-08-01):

# 01 项目介绍

| 项目 | 内容 |
|---|---|
| 项目名称 | Robot_Treasure |
| 目标比赛 | 2026 江苏省大学生机器人大赛——密室夺宝项目 |
| 项目目标 | 制作一台能够自主循迹、检测敌方、获取宝藏并进行声光提示的 STM32 机器人 |
| 当前版本 | v0.1.0（工程骨架） |
| 当前开发状态 | 方案初步确定，等待规则确认、器件选型和 CubeMX 初始化 |

## 阶段目标

`规则确认 → 硬件选型 → 分模块调试 → 整车联调 → 赛场测试`

## 当前范围

- 建立项目目录与文档。
- 建立 STM32 软件分层骨架。
- 暂不实现完整程序和复杂算法。

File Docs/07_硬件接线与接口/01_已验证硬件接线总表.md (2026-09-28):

# 已验证硬件接线总表

本表只记录已实际连接、使用或完成硬件验证的内容。未接入的第二块 NCHD12、其余 ToF、普通红外的最终整车安装与永久分配方案、蜂鸣器、外部 LED、电池 ADC、外部 DC-DC 与板载 TFT 不在本表中。

## 供电与共地

| 起点 | 终点 | 状态 | 说明 |
|---|---|---|---|
| 3S 锂电池正极 | MD240A `VIN/VM` | 已实机验证 | 台架测试已使用的动力输入。 |
| 3S 锂电池负极 | MD240A `GND` | 已实机验证 | 电池极性不得凭线色猜测，接线前复核端子标识。 |
| MD240A `VOUT 5V` | STM32 开发板 `5V` | 已实机验证 | 当前台架 STM32 供电路径。 |
| MD240A `GND` | STM32 开发板 `GND` | 已实机验证 | 控制与动力共地。 |
| STM32 `5V/GND` | 第一块 NCHD12 `VCC/GND` | 已实机验证 | 当前已验证灰度模块供电。 |
| 编码器 `VCC` | 实际供电电压 | 已连接但具体参数待确认 | 编码器信号已实机验证；现有文字记录未能独立确认 VCC 实际接入 3.3V 还是 5V，后续须结合实物线束和商家引脚定义补录。 |

电机动力仅走电池至 MD240A 的路径。MD240A、STM32、编码器、第一块 NCHD12 与 CH340 使用共同 GND；外部 DC-DC 不得与当前 MD240A `VOUT 5V` 并联。

## 四路电机驱动与物理轮位

从 11C 开始，当前物理轮位为：`B=FL=左前`、`A=FR=右前`、`D=RL=左后`、`C=RR=右后`。信号方向均为 **STM32 输出 → MD240A 控制输入**。11D-1 已确认车辆前进时 B/A 使用 ELEC_REV、D/C 使用 ELEC_FWD；车辆后退使用相反电气方向。ELEC_FWD/ELEC_REV 仅表示 IN1/IN2 电气组合，不能脱离当前车头解释。

| 驱动通道 | 物理轮位 | PWM（定时器） | IN1 | IN2 | 公共使能 | 验证状态 |
|---|---|---|---|---|---|---|
| A | FR 右前 | PC6（TIM8_CH1） | PC0 | PC1 | PC2 `STY/STBY` | 车辆前进=ELEC_REV，已实机验证 |
| B | FL 左前 | PC7（TIM8_CH2） | PC3 | PC4 | PC2 `STY/STBY` | 车辆前进=ELEC_REV，已实机验证 |
| C | RR 右后 | PA1（TIM5_CH2） | PC5 | PB0 | PC2 `STY/STBY` | 车辆前进=ELEC_FWD，已实机验证 |
| D | RL 左后 | PA2（TIM5_CH3） | PB1 | PA10 | PC2 `STY/STBY` | 车辆前进=ELEC_FWD，已实机验证 |

MD240A A/B/C/D 各通道的两根电机动力线，分别接 FR/FL/RR/RL 对应电机的两根动力线。电机线颜色未有可靠资料，不记录或推断线色。11D-1 在 PWM=180/999 下已确认四路均可连续转动，未使用 B 专用固定 PWM 补偿；11D-2 已在前进直行落地测试中确认四轮独立 PI 可将最终转速稳定在约 77～79 RPM，B 最大 PWM 为 246（上限 300），无长期 PI 饱和。该结论不包含后退或转向动作。若交换任一电机两根动力线，该轮电气方向会反转，软件映射必须重新验证。

## 四路编码器

编码器 A/B 相均为 **编码器输出 → STM32 定时器编码器输入**；四路采用 AB 相正交输入，软件统一按 `1560 count/rev` 计算。逻辑符号 `-1/+1` 用于统一车轮正方向，并非接线极性。

| 编码器 | 物理轮位 | 驱动通道 | A 相 | B 相 | 定时器 | 逻辑符号 | 验证状态 |
|---|---|---|---|---|---|---:|---|
| A | FR 右前 | A | PA6 | PA7 | TIM3 | -1 | 车辆前进原始计数为负，已实机验证 |
| B | FL 左前 | B | PB6 | PB7 | TIM4 | +1 | 车辆前进原始计数为正，已实机验证 |
| C | RR 右后 | C | PA15 | PB3 | TIM2（部分重映射） | -1 | 车辆前进原始计数为负，已实机验证 |
| D | RL 左后 | D | PA8 | PA9 | TIM1 | +1 | 车辆前进原始计数为正，已实机验证 |

六芯线颜色与具体插头针序尚无可靠资料，不得猜测；电机动力线和编码器信号线须分开描述与布线。

## 第一块 NCHD12 灰度模块

| 模块端 | STM32 端 | 方向/配置 | 验证状态 |
|---|---|---|---|
| GND | GND | 共地 | 已实机验证 |
| VCC | 5V | 4 针 I2C 接口供电 | 已实机验证 |
| SCL | PB8 / I2C1_SCL | I2C1 重映射，100 kHz | 已实机验证 |
| SDA | PB9 / I2C1_SDA | I2C1 重映射，100 kHz | 已实机验证 |

7 位地址为 `0x20`，HAL 访问使用 `addr7 << 1`。P1=B0、P2=B1，依次至 P12=B11；B12～B15 不是灰度通道。黑色=1、白色=0，故全白 `GRAY12=0x000`、全黑 `GRAY12=0xFFF`。模块 P1～P12 的独立数字输出排针当前未接 STM32。

11C 已确认当前安装关系：P12 侧为 `VEHICLE_LEFT`，P1 侧为 `VEHICLE_RIGHT`。标签坐标 P1 侧为负、P12 侧为正；车辆误差按 `vehicle_error_x100 = -label_position_x100` 转换，因此车辆左为负、右为正。无黑线和全黑状态的车辆误差保持 `INVALID`，不伪造有效的零误差。

## AI-1811 激光测距模块（历史验证，当前已拆除）

| 模块端 | STM32 端 | 方向/配置 | 验证状态 |
|---|---|---|---|
| `V` | `3.3V` | 模块供电 | 已实机验证 |
| `G` | `GND` | 共地 | 已实机验证 |
| `T` | PA3 / USART2_RX | AI-1811 主动上报 → STM32；USART2 为 RX Only，115200、8N1 | 已实机验证 |
| `R` | 当前不接 | 本次基础读取不向模块发送命令 | 已实机验证 |

12B 实测连续稳定收到固定 8 字节帧 `AA 05 FW_L FW_H DIST_L DIST_H CONF SUM`；`FW`、`DIST` 为小端，`DIST` 单位为 mm，`SUM` 为前 7 字节累加和的低 8 位。以上内容保留为历史实机验证事实；当前整车不再使用 AI-1811，模块已从 PA3 拆除，PA3 不再计入当前占用。PA2 继续作为电机 D 路 PWM，USART3 PB10/PB11 继续作为 CH340 调试串口。

## 普通红外前向单路测试（12A/13A）

| 模块端 | STM32 端 | 方向/配置 | 验证状态 |
|---|---|---|---|
| `VCC` | `3.3V` | 模块供电 | 已实机验证 |
| `GND` | `GND` | 共地 | 已实机验证 |
| `OUT` | `PB14` | GPIO 输入、`GPIO_NOPULL`；低电平为 `DETECTED`，高电平为 `CLEAR` | 已实机验证 |

12A 在当前电位器设置下测试了白色目标和黑色非亮面目标，约 10 cm 处均可稳定触发，连续串口采样未观察到明显抖动。13A 已实机确认同一单路接口可在连续障碍检测后触发一次车辆动作联动：先停车约 200 ms，再以 30 RPM 后退约 1 s，随后自动停车。当前计划沿用 PB14 作为前向红外；新增左、后、右三路尚未实机验证，记录在 `03_后续硬件扩展预留.md`。本记录不延伸为 ABS、材质或敌方机器人识别、最终安装或最终检测距离结论。

## CH340 调试串口

| STM32 端 | CH340 端 | 信号方向 | 验证状态 |
|---|---|---|---|
| PB10 / USART3_TX | RXD | STM32 → CH340 | 已实机验证 |
| PB11 / USART3_RX | TXD | CH340 → STM32 | 已实机验证 |
| GND | GND | 共地 | 已实机验证 |

UART 必须交叉连接；当前参数为 115200、8N1。只查看 STM32 输出时，PB11/CH340 TXD 可不接。Windows 分配的 COM11、COM12 等 COM 号不是硬件接线。USART3 当前为调试串口，不能同时直接接入主动上报 ToF。

## ST-Link 与板载按键

| 对象 | STM32 端 | 接线/电平 | 状态 |
|---|---|---|---|
| ST-Link SWDIO | PA13 / SWDIO | ST-Link → STM32 SWD 调试 | 已实机验证 |
| ST-Link SWCLK | PA14 / SWCLK | ST-Link → STM32 SWD 调试 | 已实机验证 |
| ST-Link GND | GND | 共地 | 已实机验证 |
| ST-Link NRST | NRST | 可选；现有记录未证明已连接 | 未确认（可选） |
| ST-Link 3.3V/VTref | 目标电压参考/特定供电方式 | 不得与其他供电源并联，是否实际连接按现场确认 | 未确认（可选） |
| WK_UP | PA0 | 板载、按下高电平、下拉输入 | 已实机验证 |
| KEY1 | PC9 | 板载、按下低电平、上拉输入 | 已实机验证 |
| KEY2 | PC8 | 板载、按下低电平、上拉输入 | 已实机验证 |

三个按键均为开发板内连接，不需外接杜邦线，但仍占用对应 STM32 引脚。板载 1.44 寸 TFT 已焊接在开发板上；当前工程没有启用，且仓库缺少可独立确认的完整 TFT 引脚表，因此不分配或猜测其引脚。

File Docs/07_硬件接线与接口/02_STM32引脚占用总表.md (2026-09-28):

# STM32 引脚占用总表

当前占用以 `STM32/Keil_Project/Gray12_SideTurn_LineFollow_Test/Gray12_SideTurn_LineFollow_Test.ioc` 为主要资源基线，并结合 `Infrared_Raw_Test.ioc` 的 PB14 已验证接口整理。历史 `Laser12B_AI1811_Raw_Uart_Test.ioc` 中的 PA3/USART2_RX 不再计入当前占用。状态为“仅软件配置”时，表示工程已配置该引脚；实体连接须另以 `01` 的记录为准。

| STM32 引脚 | 外设功能 | 连接对象 | 对方引脚 | 信号方向 | 所属硬件 | 当前状态 | 备注 |
|---|---|---|---|---|---|---|---|
| PA0 | GPIO 输入 | 板载 WK_UP | 板载按键 | 外部硬件输入到 STM32 | 按键 | 已实机验证 | 下拉，按下高。 |
| PA1 | TIM5_CH2 PWM | MD240A C | PWM | STM32 输出到外部硬件 | 电机驱动 | 已实机验证 | RR 右后。 |
| PA2 | TIM5_CH3 PWM | MD240A D | PWM | STM32 输出到外部硬件 | 电机驱动 | 已实机验证 | RL 左后；保持电机 PWM，不作为 USART2_TX。 |
| PA4 | GPIO 输出 | 前灰度 NCHD12 | SCL | STM32 输出到外部硬件 | 前灰度模块 | 仅软件配置 | 当前工程使用软件 I²C。 |
| PA5 | GPIO 输出 | 前灰度 NCHD12 | SDA | 双向数据 | 前灰度模块 | 仅软件配置 | 当前工程使用软件 I²C。 |
| PA6 | TIM3_CH1 | Encoder A | A 相 | 外部硬件输入到 STM32 | 编码器 | 已实机验证 | FR 右前。 |
| PA7 | TIM3_CH2 | Encoder A | B 相 | 外部硬件输入到 STM32 | 编码器 | 已实机验证 | FR 右前。 |
| PA8 | TIM1_CH1 | Encoder D | A 相 | 外部硬件输入到 STM32 | 编码器 | 已实机验证 | RL 左后。 |
| PA9 | TIM1_CH2 | Encoder D | B 相 | 外部硬件输入到 STM32 | 编码器 | 已实机验证 | RL 左后。 |
| PA10 | GPIO 输出 | MD240A D | IN2 | STM32 输出到外部硬件 | 电机驱动 | 已实机验证 | RL 左后。 |
| PA13 | SWDIO | ST-Link | SWDIO | 双向或调试连接 | 调试下载 | 已实机验证 | SWD。 |
| PA14 | SWCLK | ST-Link | SWCLK | 双向或调试连接 | 调试下载 | 已实机验证 | SWD。 |
| PA15 | TIM2_CH1 | Encoder C | A 相 | 外部硬件输入到 STM32 | 编码器 | 已实机验证 | TIM2 部分重映射，RR 右后。 |
| PB0 | GPIO 输出 | MD240A C | IN2 | STM32 输出到外部硬件 | 电机驱动 | 已实机验证 | RR 右后。 |
| PB1 | GPIO 输出 | MD240A D | IN1 | STM32 输出到外部硬件 | 电机驱动 | 已实机验证 | RL 左后。 |
| PB3 | TIM2_CH2 | Encoder C | B 相 | 外部硬件输入到 STM32 | 编码器 | 已实机验证 | TIM2 部分重映射，RR 右后。 |
| PB4 | GPIO 输出 | 板载 TFT | BLK | STM32 输出到板载硬件 | TFT | 仅软件配置 | 当前工程软件驱动 TFT。 |
| PB5 | GPIO 输出 | 板载 TFT | RS/DC | STM32 输出到板载硬件 | TFT | 仅软件配置 | 当前工程软件驱动 TFT。 |
| PB6 | GPIO 输出 | 板载 TFT | RST | STM32 输出到板载硬件 | TFT | 仅软件配置 | 当前工程软件驱动 TFT。 |
| PB7 | GPIO 输出 | 板载 TFT | CS | STM32 输出到板载硬件 | TFT | 仅软件配置 | 当前工程软件驱动 TFT。 |
| PB8 | GPIO 输出 | 板载 TFT | SCLK | STM32 输出到板载硬件 | TFT | 仅软件配置 | 当前工程软件 SPI 时钟。 |
| PB9 | GPIO 输出 | 板载 TFT | MOSI | STM32 输出到板载硬件 | TFT | 仅软件配置 | 当前工程软件 SPI 数据。 |
| PB10 | USART3_TX | CH340 | RXD | STM32 输出到外部硬件 | 调试串口 | 已实机验证 | 115200、8N1。 |
| PB11 | USART3_RX | CH340 | TXD | 外部硬件输入到 STM32 | 调试串口 | 已实机验证 | 115200、8N1。 |
| PB12 | GPIO 输出 | 后灰度 NCHD12 | SCL | STM32 输出到外部硬件 | 后灰度模块 | 仅软件配置 | 当前工程使用软件 I²C。 |
| PB13 | GPIO 输出 | 后灰度 NCHD12 | SDA | 双向数据 | 后灰度模块 | 仅软件配置 | 当前工程使用软件 I²C。 |
| PB14 | GPIO 输入 | 前向普通红外模块 | `OUT` | 外部硬件输入到 STM32 | 普通红外（12A/13A） | 已实机验证 | `GPIO_NOPULL`；低电平 `DETECTED`、高电平 `CLEAR`。当前计划沿用为前向接口。 |
| PC0 | GPIO 输出 | MD240A A | IN1 | STM32 输出到外部硬件 | 电机驱动 | 已实机验证 | FR 右前。 |
| PC1 | GPIO 输出 | MD240A A | IN2 | STM32 输出到外部硬件 | 电机驱动 | 已实机验证 | FR 右前。 |
| PC2 | GPIO 输出 | MD240A | STY/STBY | STM32 输出到外部硬件 | 电机驱动 | 已实机验证 | 四路公共使能。 |
| PC3 | GPIO 输出 | MD240A B | IN1 | STM32 输出到外部硬件 | 电机驱动 | 已实机验证 | FL 左前。 |
| PC4 | GPIO 输出 | MD240A B | IN2 | STM32 输出到外部硬件 | 电机驱动 | 已实机验证 | FL 左前。 |
| PC5 | GPIO 输出 | MD240A C | IN1 | STM32 输出到外部硬件 | 电机驱动 | 已实机验证 | RR 右后。 |
| PC6 | TIM8_CH1 PWM | MD240A A | PWM | STM32 输出到外部硬件 | 电机驱动 | 已实机验证 | FR 右前。 |
| PC7 | TIM8_CH2 PWM | MD240A B | PWM | STM32 输出到外部硬件 | 电机驱动 | 已实机验证 | FL 左前。 |
| PC8 | GPIO 输入 | 板载 KEY2 | 板载按键 | 外部硬件输入到 STM32 | 按键 | 已实机验证 | 上拉，按下低。 |
| PC9 | GPIO 输入 | 板载 KEY1 | 板载按键 | 外部硬件输入到 STM32 | 按键 | 已实机验证 | 上拉，按下低。 |
| PC10 | GPIO/EXTI 输入 | Encoder B | A 相 | 外部硬件输入到 STM32 | 编码器 | 仅软件配置 | 当前整车工程的新接口。 |
| PC11 | GPIO/EXTI 输入 | Encoder B | B 相 | 外部硬件输入到 STM32 | 编码器 | 仅软件配置 | 当前整车工程的新接口。 |
| PC12 | UART5_TX | JY61P `RX` | UART 数据 | STM32 输出到外部硬件 | JY61P 六轴姿态传感器 | 已接线，待软件验证 | 与 JY61P `RX` 交叉连接；后续用于配置模块参数。 |
| PD2 | UART5_RX | JY61P `TX` | UART 数据 | 外部硬件输入到 STM32 | JY61P 六轴姿态传感器 | 已接线，待软件验证 | 接收 JY61P 默认 UART 姿态数据；后续用于相对 90° 转弯。 |

## 当前空闲 / 未分配

上表之外的引脚不能直接视为可用。它们可能未在当前 `.ioc` 配置，却仍可能受板载 TFT、开发板排针未引出、晶振、下载接口或复用限制影响。对这类引脚的唯一可用表述是：**未在当前 `.ioc` 占用，但开发板板载连接和实际引出状态待原理图确认。** 新功能应先确认开发板原理图、实体引出和复用冲突，再更新 `.ioc`、驱动与本表。

### 四方向普通红外接口计划

| 方向 | 候选 GPIO | 当前冲突检查 | 状态 |
|---|---|---|---|
| 前 | PB14 | 已验证普通红外单路输入；与当前主要资源无冲突 | 已实机验证，计划沿用 |
| 左 | PA3 | 原 AI-1811 已拆除；当前主要 `.ioc` 未占用，且 PA2 电机 PWM 不受影响 | 计划分配，尚未验证 |
| 后 | PB15 | 当前主要 `.ioc` 未占用；PB12/PB13 已用于后灰度，不可替代 | 计划分配，尚未验证；确认实体引出后接线 |
| 右 | PA11 | 当前主要 `.ioc` 未占用；不影响 PA10 电机方向或 PA13/PA14 SWD | 计划分配，尚未验证；确认实体引出且未接 USB 后接线 |

新增三路均计划配置为 `GPIO Input`、`GPIO_NOPULL`，沿用同型号模块的 `VCC→3.3V`、`GND→GND`、低电平 `DETECTED` 方案；在新增三路完成实机测试前，不得写成已验证事实。

## JY61P 已接线、待软件验证

JY61P 已按 UART5 接线：`VCC→5V`、`GND→GND`、`TX→PD2/UART5_RX`、`RX→PC12/UART5_TX`。当前仅确认实体接线，尚未配置 UART5、解析姿态帧或完成角度数据实测，不能写为通信已验证。

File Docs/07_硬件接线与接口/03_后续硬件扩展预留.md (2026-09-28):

# 后续硬件扩展预留

本文件记录尚未作为整车最终方案完成的扩展计划。AI-1811 的单模块 UART 接收保留历史验证记录，但当前整车不再使用该模块，PA3 已释放给普通红外扩展候选。其余项目仍不得在已验证接线中写成已完成。设计前须先阅读 [02_STM32引脚占用总表.md](02_STM32引脚占用总表.md)。

| 项目 | 当前计划 | 引脚/供电约束 | 状态 |
|---|---|---|---|
| 第二块 NCHD12 | 当前整车工程按前、后两块软件 I²C 分开配置。 | 前灰度 `PA4=SCL`、`PA5=SDA`；后灰度 `PB12=SCL`、`PB13=SDA`。当前仅作为软件资源占用，实体接线和实机结果另行验证。 | 仅软件配置，实机待验证 |
| AI-1811 ToF 单模块 | 当前整车不再使用；仅保留 12B 历史验证资料和测试工程。 | 已从 PA3 拆除；PA3 不再计入激光传感器占用。 | 历史验证完成，当前停用 |
| 四方向普通红外模块 | 保留现有前向 PB14，再新增左、后、右三路。 | 前 `PB14`（已验证）；左 `PA3`、后 `PB15`、右 `PA11`（计划）。新增三路计划使用 `GPIO Input`、`GPIO_NOPULL`；同型号模块按 `VCC→3.3V`、`GND→GND`、低电平 `DETECTED` 接入。PA11/PB15 接线前确认开发板实体引出，PA11 不得同时接 USB。 | 前向单路已验证；左/后/右待接线与实机验证 |
| JY61P 六轴姿态传感器 | 用相对航向角辅助 90° 原地转向，最终仍需由灰度确认线路。 | 已实体接线：`VCC→5V`、`GND→GND`、`TX→PD2/UART5_RX`、`RX→PC12/UART5_TX`。 | 已接线，UART5 配置、协议解析和实机角度验证待完成 |
| 蜂鸣器 | 声音提示候选。 | GPIO 与驱动方式尚未分配。 | 仅后续计划 |
| 外部状态 LED | 状态提示候选。 | GPIO 与限流/电平方案尚未分配。 | 仅后续计划 |
| 电池电压 ADC | 电量采样候选。 | ADC 引脚、分压网络和参考电压尚未确认。 | 仅后续计划 |
| 外部 DC-DC 最终供电 | 整车可能由电池控制支路经 DC-DC 给 STM32 和传感器供电。 | 切换前用万用表确认输出电压与极性；DC-DC 5V 不得与 MD240A `VOUT 5V` 并联。 | 仅后续计划 |
| 板载 1.44 寸 TFT | 板载但当前工程未启用。 | 缺少可独立确认的完整引脚表；获得原理图并验证前不分配引脚。 | 仅后续计划 |

## 扩展实施门槛

- 先检查当前占用和开发板实际引出，不能预填不存在的 GPIO、ADC 或 UART 分配。
- 新增三路红外完成接线后，须逐路遮挡确认方向映射、有效电平和是否存在串扰，再将结果迁入 `01`。
- 外部 DC-DC 切换前确认电压和极性；切换后保持单一 STM32 供电源与全系统共地。
- 每项完成实体接线与实机测试后，补充实测条件和结论，再迁入 `01` 与 `02`。

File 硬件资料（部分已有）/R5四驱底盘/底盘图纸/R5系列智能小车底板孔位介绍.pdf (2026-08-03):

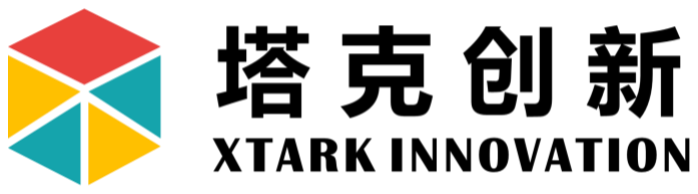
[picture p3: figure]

## R5底板孔位介绍

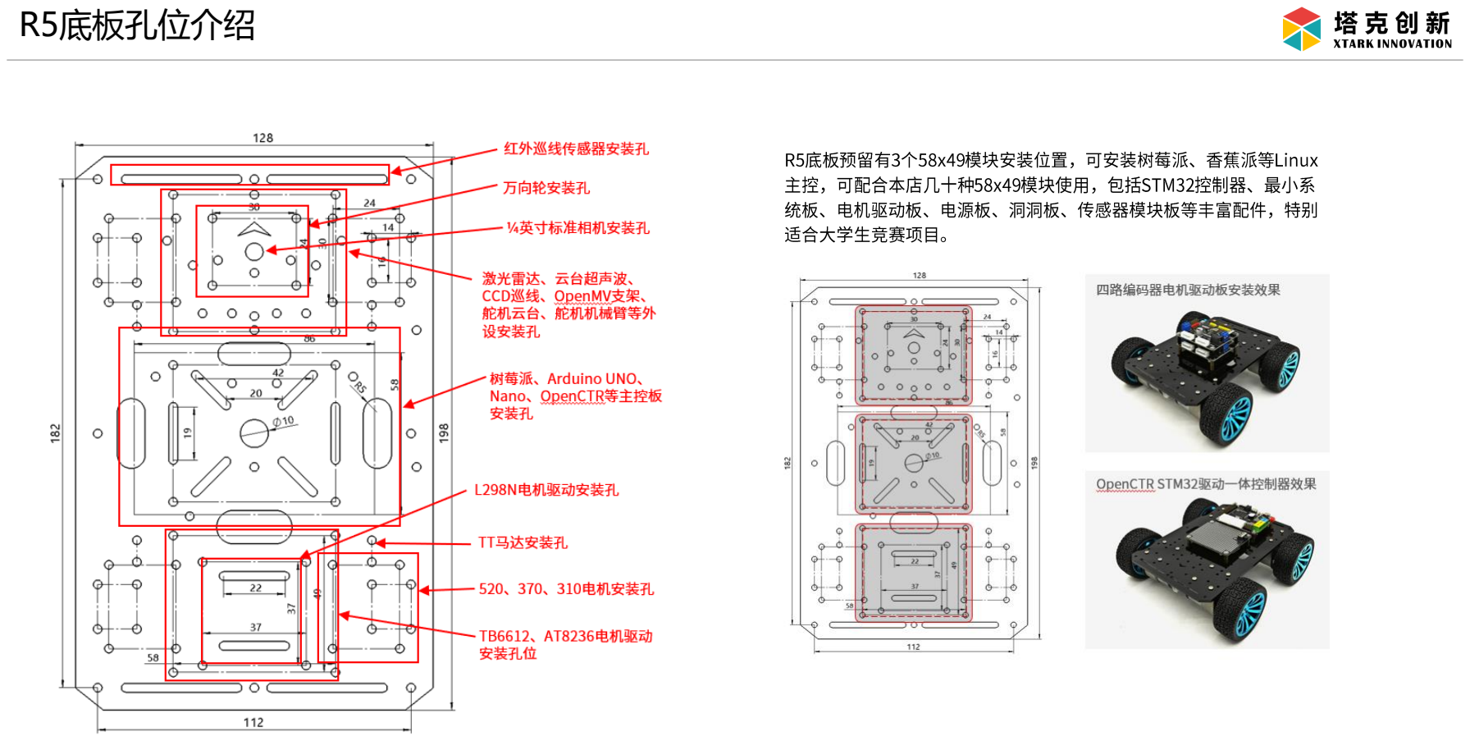
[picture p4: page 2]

## R5底板孔位介绍

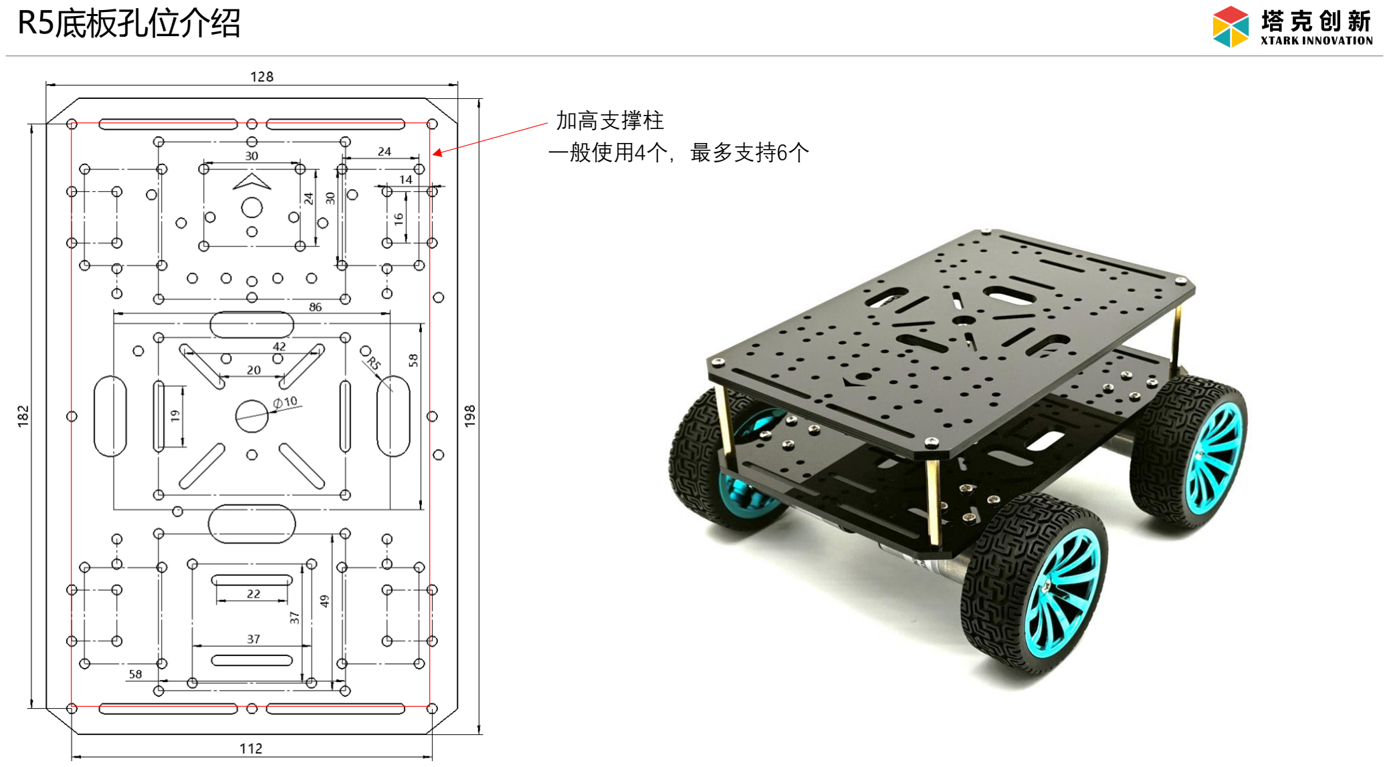
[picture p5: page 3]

一般使用4个，最多支持6个

加高支撑柱

## R5底板孔位介绍

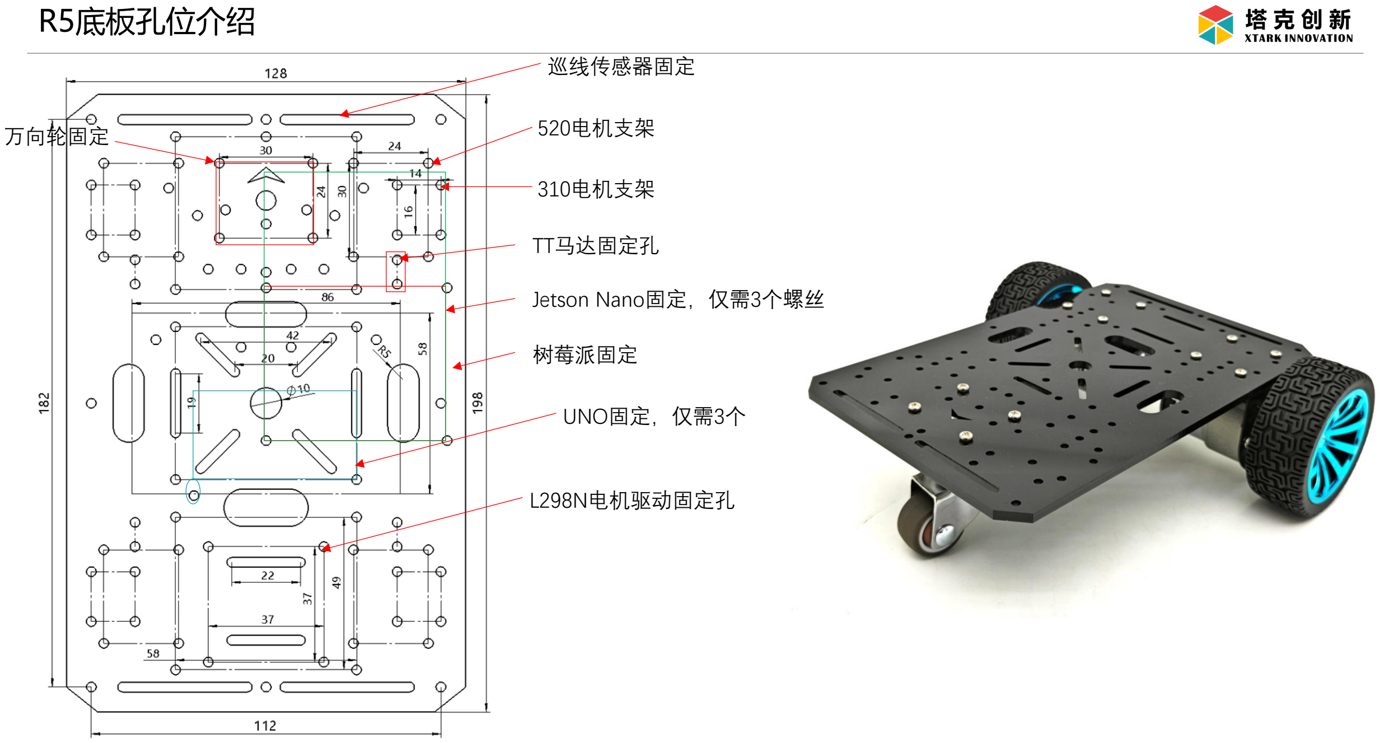
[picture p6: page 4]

520电机支架

310电机支架

TT马达固定孔

Jetson Nano固定，仅需3个螺丝

树莓派固定

UNO固定，仅需3个

巡线传感器固定

L298N电机驱动固定孔

万向轮固定

## R5底板孔位介绍

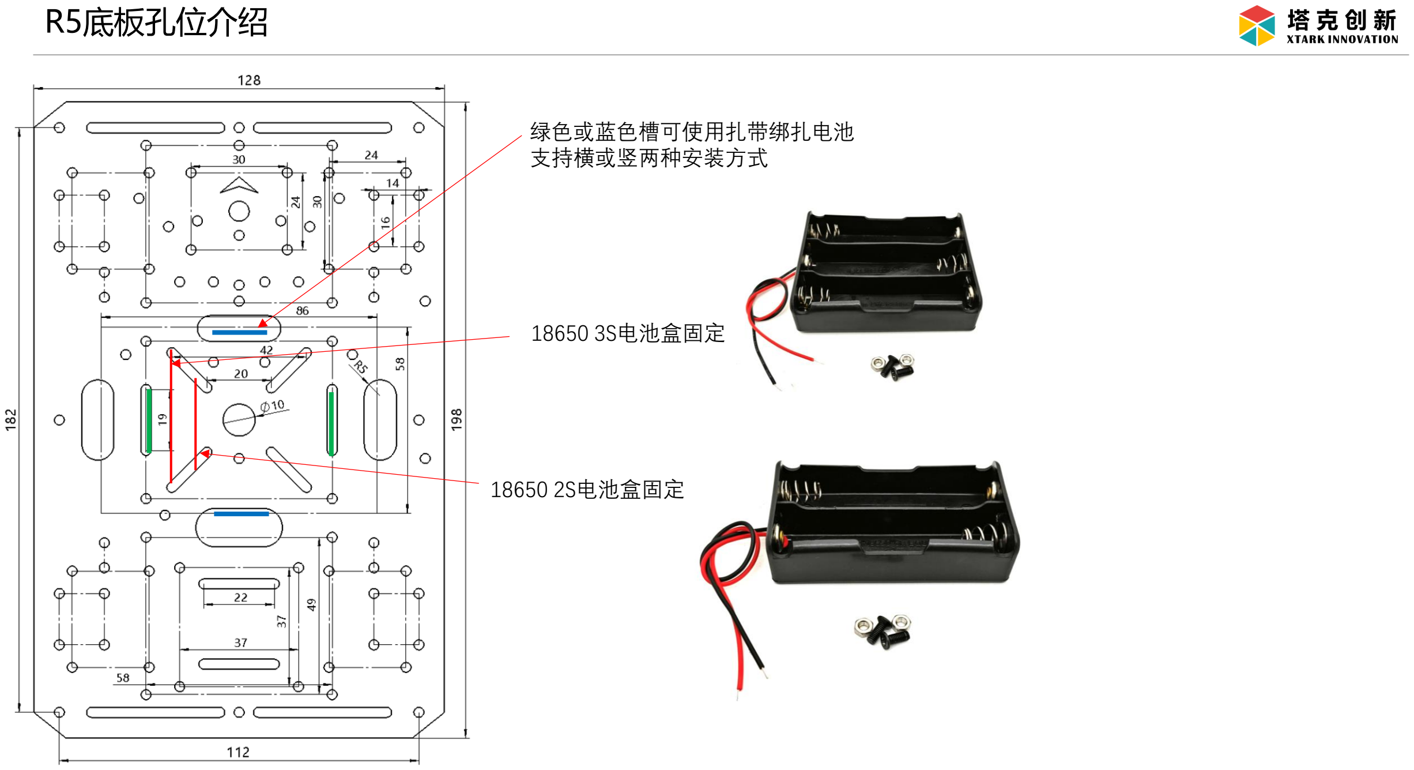
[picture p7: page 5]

18650 3S电池盒固定

18650 2S电池盒固定

绿色或蓝色槽可使用扎带绑扎电池
支持横或竖两种安装方式

## R5底板孔位介绍

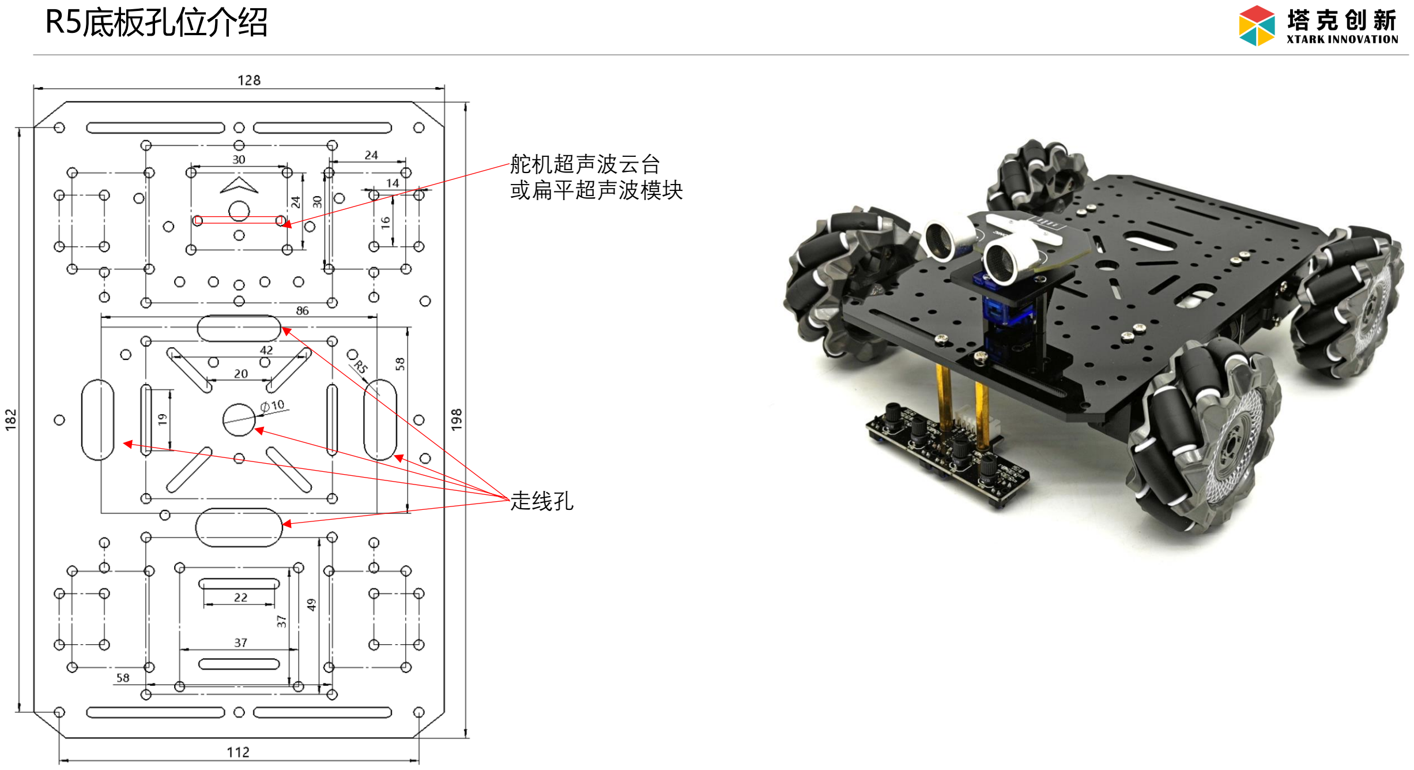
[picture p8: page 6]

舵机超声波云台
或扁平超声波模块

走线孔

## R5底板孔位介绍

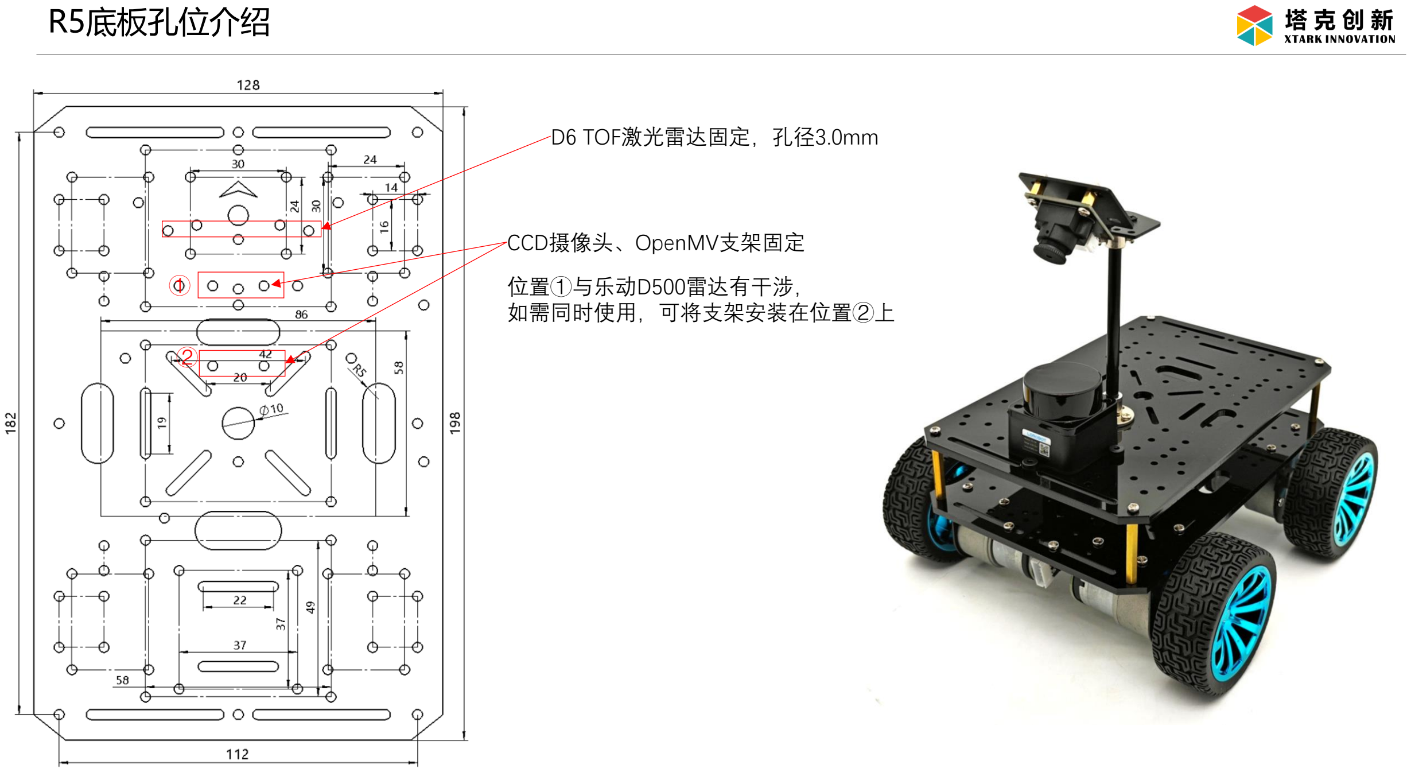
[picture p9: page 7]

D6 TOF激光雷达固定，孔径3.0mm

CCD摄像头、OpenMV支架固定

位置①与乐动D500雷达有干涉，
如需同时使用，可将支架安装在位置②上

①

②

## R5底板孔位介绍

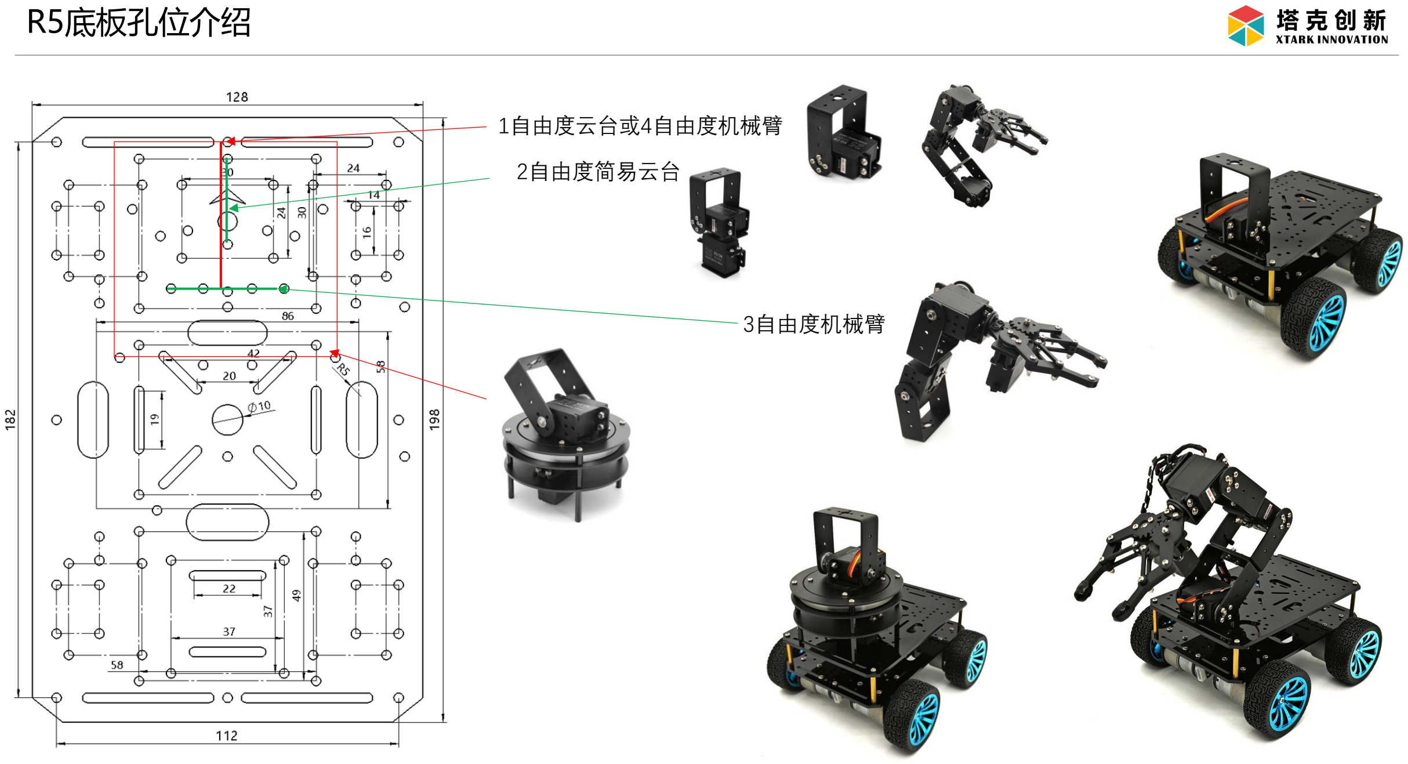
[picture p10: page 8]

1自由度云台或4自由度机械臂

2自由度简易云台

3自由度机械臂

## R5底板孔位介绍

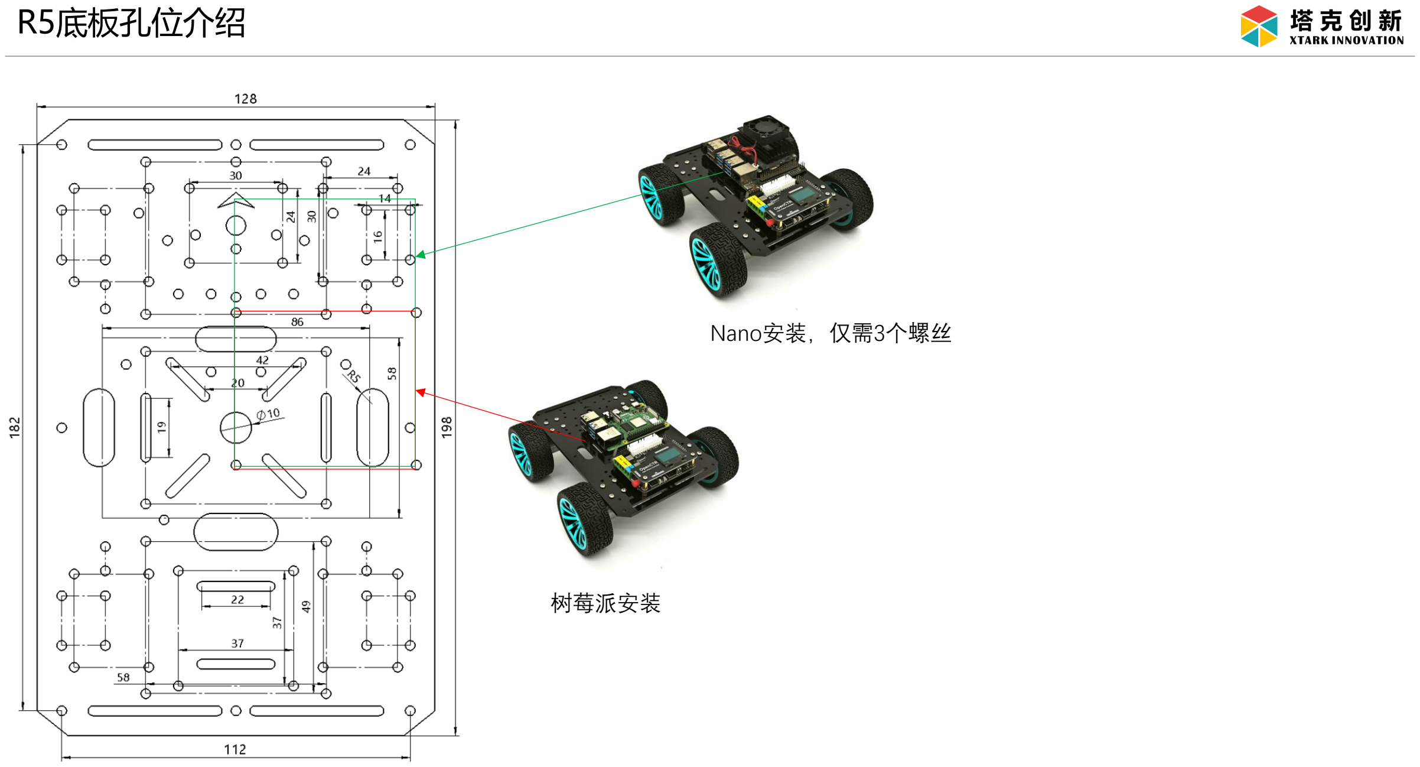
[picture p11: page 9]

树莓派安装

Nano安装，仅需3个螺丝

## R5底板孔位介绍

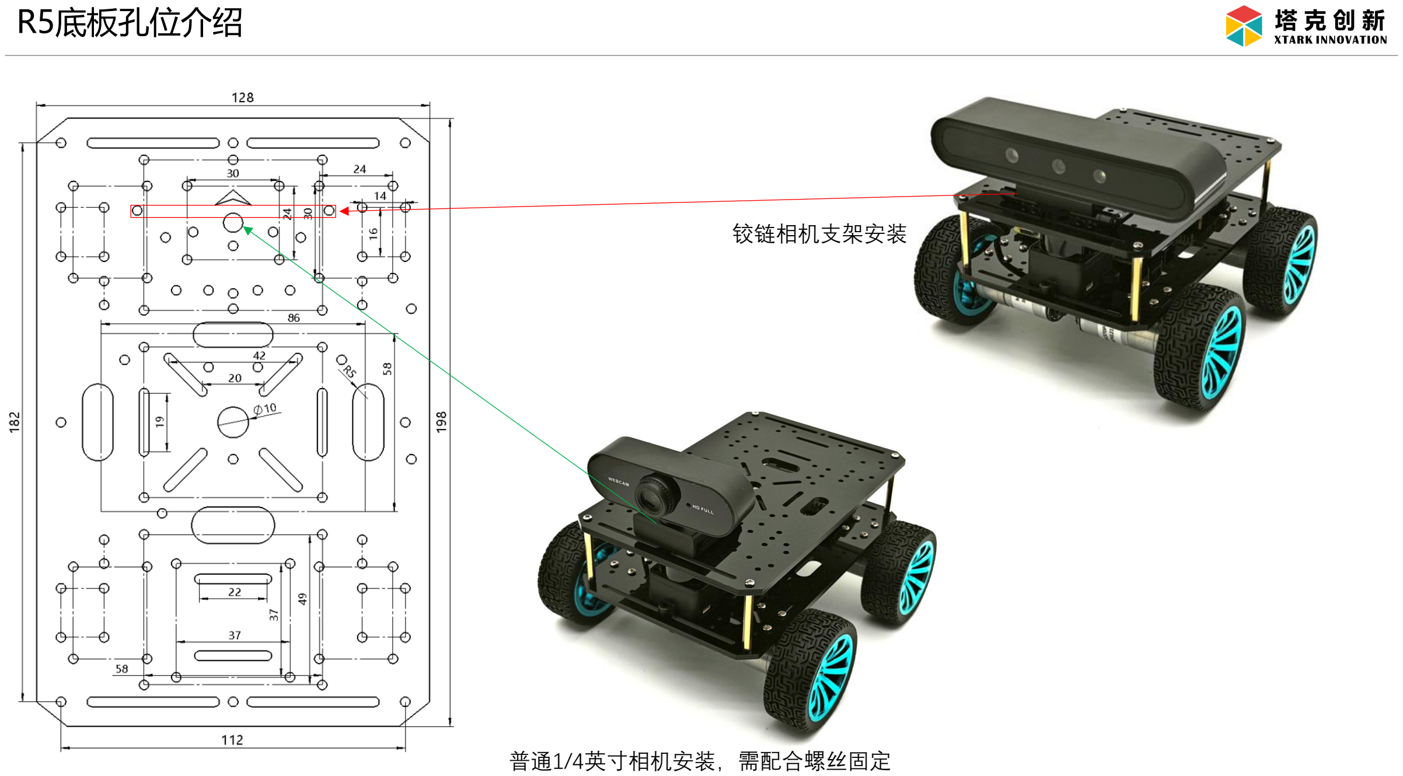
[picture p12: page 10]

铰链相机支架安装

普通1/4英寸相机安装，需配合螺丝固定

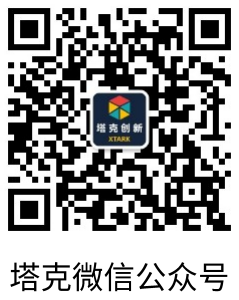
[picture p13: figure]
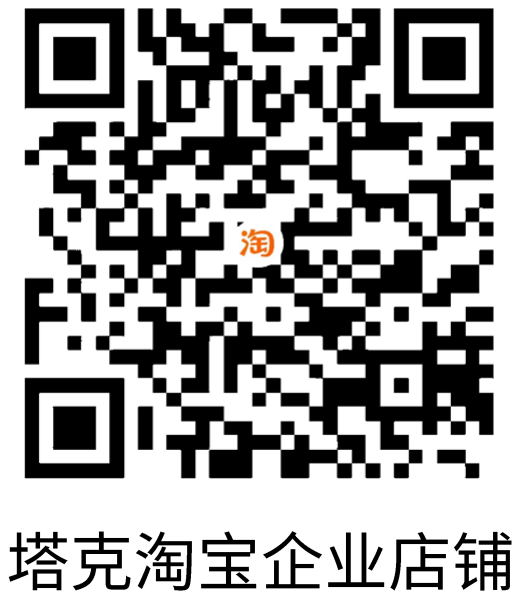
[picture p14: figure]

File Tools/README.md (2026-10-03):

# 密室夺宝电脑端成果

本目录收录本次聊天形成的地图规划和双车追逃仿真最终成果。当前策略的自然语言说明见 [小偷与警察策略](../Docs/08_夺宝对抗策略说明.md)。

- [TreasureRoutePlanner](TreasureRoutePlanner/README.md)：原图、道路数据、路径规划程序、测试、计算结果及路线图。其策略说明保留早期静态分析，当前动态策略以仿真目录和上面的策略文档为准。
- [TreasurePursuitSimulator](TreasurePursuitSimulator/README.md)：当前追逃策略、参数、七场景回放、稳定节点与路段数据、测试及验证截图。

下载仓库后可直接用浏览器打开 `TreasurePursuitSimulator/replay.html`。GitHub 文件预览不会直接运行交互回放。

## 验证

在仓库根目录运行：

```powershell
python -m unittest discover -s Tools/TreasureRoutePlanner
python -m unittest discover -s Tools/TreasurePursuitSimulator
node Tools/TreasurePursuitSimulator/qa/verify_annotations.cjs
```

提交前实际通过：地图规划 8 项测试、仿真 100 项测试、七局回放输出核查。仅为电脑仿真验证，未执行 STM32 编译或硬件测试。

## 交付范围

各工具 README 中早期的“尚未跟踪、未提交”及阶段清单为当时工作记录。本次将下列最终文件纳入版本管理；临时备份、旧版 `baseline_v1.py`、历史 QA 对比、缓存留在本地，不作为当前运行依赖。

验证脚本使用 `qa/reference-map.json` 保存的早期原地图基准进行比较，不再依赖本地备份目录。保留桌面、手机标注截图和最新 `pocket-fix.jpg`；桌面/手机截图用于展示此前标注验证，最新策略回放以 `replay.html` 为准。

### 本次新增到 Git 的文件

- `Tools/README.md`
- `Tools/TreasurePursuitSimulator/.gitignore`
- `Tools/TreasurePursuitSimulator/config.json`
- `Tools/TreasurePursuitSimulator/escape_routes.json`
- `Tools/TreasurePursuitSimulator/map_annotations.js`
- `Tools/TreasurePursuitSimulator/map_annotations.json`
- `Tools/TreasurePursuitSimulator/map_annotations.py`
- `Tools/TreasurePursuitSimulator/qa/annotations-desktop.jpg`
- `Tools/TreasurePursuitSimulator/qa/annotations-mobile.jpg`
- `Tools/TreasurePursuitSimulator/qa/pocket-fix.jpg`
- `Tools/TreasurePursuitSimulator/qa/reference-map.json`
- `Tools/TreasurePursuitSimulator/qa/refuge-labels-audit.json`
- `Tools/TreasurePursuitSimulator/qa/verify_annotations.cjs`
- `Tools/TreasurePursuitSimulator/README.md`
- `Tools/TreasurePursuitSimulator/replay.html`
- `Tools/TreasurePursuitSimulator/replay.template.html`
- `Tools/TreasurePursuitSimulator/report.json`
- `Tools/TreasurePursuitSimulator/simulate.py`
- `Tools/TreasurePursuitSimulator/test_annotations.py`
- `Tools/TreasurePursuitSimulator/test_patrol.py`
- `Tools/TreasurePursuitSimulator/test_pockets.py`
- `Tools/TreasurePursuitSimulator/test_refuge.py`
- `Tools/TreasurePursuitSimulator/test_simulate.py`
- `Tools/TreasureRoutePlanner/.gitignore`
- `Tools/TreasureRoutePlanner/build_visuals.py`
- `Tools/TreasureRoutePlanner/escape_cycles.png`
- `Tools/TreasureRoutePlanner/map.json`
- `Tools/TreasureRoutePlanner/map_graph.svg`
- `Tools/TreasureRoutePlanner/planner.py`
- `Tools/TreasureRoutePlanner/README.md`
- `Tools/TreasureRoutePlanner/reference_map.png`
- `Tools/TreasureRoutePlanner/results.json`
- `Tools/TreasureRoutePlanner/route_paths.png`
- `Tools/TreasureRoutePlanner/test_planner.py`
- `Tools/TreasureRoutePlanner/策略说明.md`

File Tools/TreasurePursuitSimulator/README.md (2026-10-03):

# 密室夺宝：有限检测、藏点转移与地图标注

这是电脑上的离线策略仿真。双方预存地图；策略使用自身位置、地图先验、有限检测及检测历史。未检测到的对手真值不会传给策略。画面显示双方真值用于复盘，裁定器使用真值判断接触。

## 打开与重新生成

直接双击 `replay.html` 即可离线观看，不需要服务器或外网。也可以使用本机入口 http://127.0.0.1:8765/replay.html 。本机服务停止时，直接打开 HTML 或在仓库根目录运行：

```powershell
python -m http.server 8765 --bind 127.0.0.1 --directory Tools/TreasurePursuitSimulator
```

修改参数后，在仓库根目录运行：

```powershell
python Tools/TreasurePursuitSimulator/simulate.py --seeds 1
python -m unittest discover -s Tools/TreasurePursuitSimulator
node Tools/TreasurePursuitSimulator/qa/verify_annotations.cjs
```

仿真只使用 Python 标准库。`--sweep` 额外比较 6 倍与 7 倍速度，`--seeds` 增加随机漏检样本。生成 `report.json`、`replay.html`、`escape_routes.json` 和 `map_annotations.json`。HTML 内嵌回放、标注脚本与地图，不依赖旁边的脚本文件；HTTP 页面导出配套 JSON，直接打开 HTML 则导出内嵌 JSON。重新生成后刷新网页。

## 这次策略修改

小偷过去每到一个网格细分点就重算远期路线，相对检测方向改变时又清除原计划，容易在同一条横线上反复折返。现在选择通往明确路口或藏点的完整路线，持续执行到目标；只有当前新检出的威胁显示下一段即将交会时，才提前换路。允许原路后退，后退与转弯都按实际等待成本比较。

针对截图对应位置 `(3,2)`、警方从右侧接近的复现测试，智能与预设两种模式均选择先到 `(3,1)`，再到 `(2,1)`，即向上再左转。另一个横线复现测试选择先向远端撤离再转下，不在下个节点立即反向。测试复现的是具体几何状态；修改策略后原回放的秒数不再一一对应。

藏点只选环路内的真实直角拐弯、T 型或十字路口，排除死路、普通直道细分点及宝藏点；所在整条直道跨度至多三格，至少有两条不通入单出口封闭环路的环路出口；排除仅通过一个口连接外界的无分岔环路及其入口藏点。候选评分考虑远离警方预计取宝来路、警方到可检测位置的行驶与拐弯耗时、附近分岔、重复停靠和转移成本。路线先比较近期交会风险，再比较分离方向及目标位置，不把直线距离当作唯一依据。当前检测会改变区域偏好；未检测时只使用先验，不能知道警方真实位置。

新增第七个场景 **“两格检测 · 定点藏匿与下一藏点转移”**：更重视让警方搜索和拐弯的代价，到达藏点后保持停靠，实际检测到警方才撤往下一藏点。原藏身模式也保持“未检出不主动离开”的停靠规则。刚暴露的藏点有 30 秒冷却期。连续逃跑使用环路内的有限目标路线；预设模式使用无重复节点的路线卡。相同条件下两种模式可能选出同一路线，当前示例中两组藏身智能与预设结果相同。

警方统一三格检测。没有线索时优先选择能够覆盖更多尚未检查候选位置的观察点，计入行驶、转弯及重复路段的代价。完整覆盖一轮后再开始新一轮，必要的过路不禁止。检出立即追踪；漏检后保留最后检测位置和方向线索，若尚未越过则先到最后位置，再沿最后方向查到直道末端后恢复搜索，或线索超过 12 秒时恢复搜索，不会因漏检返回初始取宝路线。

完整死路支路的节点及段中点均在检测范围内时，连续三次未检出后标记已查，可跳过驶入；新的侧向检出仍优先返回核查。保留连续三次确认是为了减小单次漏检的影响，并不是对实物空路的确定性证明。藏点与搜索路线都是启发式选择，未证明全局最优。

## 参数与模型边界

| 参数 | 当前设置 |
| --- | --- |
| 默认警方 / 小偷直行速度 | 1.95 / 1.95 m/s，原 0.3 m/s 的 6.5 倍 |
| 90°转弯 / 前后退换向 | 均 0.5 秒 |
| 取宝等待 | 0 秒，经过中心取得，不减速、不停车 |
| 警方检测距离 | 所有新场景均三格，0.9 米 |
| 小偷检测距离 | 按场景两格或三格，0.6 / 0.9 米 |
| 检测周期 / 漏检概率 / 四方向半角 | 20 ms / 5% / 10° |
| 二维中心接触距离 | 0.18 米 |
| 近期检测记忆 / 警方线索搜索期 | 2 秒 / 12 秒 |
| 藏点直道总跨度上限 | 三格，0.9 米 |
| 比赛时限 | 180 秒 |

后退保持车头方向，左右传感器按车头方向解释。沿线动作到下一地图节点、已开始的转向或换向完成后再执行新动作。二维连续碰撞检测包含交叉路口、原地等待及检测盲区；达到接触阈值立即结束比赛，不要求双方先识别到对方。

自身位置假设已知，检测内对手位置为理想测量。模型尚未包括实际定位误差、完整车身与旋转包络、制动与加速、循迹偏差、掉宝及取宝机构。未移植 STM32，未执行 Keil 编译，尚未完成硬件验证。`baseline_v1.py` 仅作历史参考，当前入口不调用。没有全局观测策略或警方较慢的新场景。

## 节点与路段标注

沿用 `../TreasureRoutePlanner/map.json` 的全部连接与长度：**88 个节点、106 条直线路段、121 个原图节点对应项**。压缩只合并直道上的普通细分点，不增加、删除或改接道路。每条原图边恰好属于一条导出路段，全部标注节点对之间的最短距离保持不变。

- “显示节点编号”和“显示路段信息”分别控制标注；节点及 N001 等编号默认开启，路段信息默认关闭。警方蓝色实线、小偷橙色虚线保留，车辆绘制在标注上层。
- 节点包括直角、T 型、十字、端点、双方出生点和宝藏点，用颜色及形状双重区分，并有图例。
- 点击节点查看编号、类型、格坐标、推算米坐标、原图键及每个相邻路段的长度、方向、相邻节点；点击路段查看两端及正反方向。下拉框可直接选择节点。
- 标签避开车辆、重要路口和其他标签。拥挤时部分路段标签省略，但道路仍可点击，完整对应关系仍在 JSON 内。手机开启标注后可单独横向滑动地图，也可用节点下拉框查看详情。
- 例如 `N023=(3,2)`，向北经 `S021` 到 `N012`，向东经 `S035` 到 `N024`，向南经 `S036` 到 `N031`，长度各 0.30 米。
- 藏点以真实节点编号显示，不放在路段中间。原图普通细分点，例如 `(4,3)`，仅以所在路段和距端点距离表达，不赋予可识别路口身份。
- `N005=(5.5,0)` 是宝藏任务位置，位于直道上，明确注明不是新增灰度路口。出生点也保留其端点几何类型。

所有长度沿用原图 0.3 米格距，**尚未实地标定**。坐标 x 向右、y 向下。相同形状的路口不能独立确定全局位置；后续定位仍需结合路口序列、行进方向和里程，识别特征需实车验证。

### JSON 与稳定编号

`map_annotations.json` 包括：

| 字段 | 用途 |
| --- | --- |
| `nodes` | 节点编号、原图键、坐标、全部类型、物理几何类型、邻接表、是否道路特征点 |
| `segments` | 路段编号、两端、长度、半格整数刻度、正反方向、原图节点序列与里程 |
| `original_node_mapping` | 全部原图节点对应的标注节点编号（或 null）、所在路段及距两端距离 |
| `identity_registry` | 编号登记表，供后续生成复用；不删除已登记编号 |
| `calibrated` / `length_note` | 未标定状态及长度来源 |

第一次按固定坐标顺序编号，之后读取已有导出文件中的登记表，保留旧编号并递增分配新编号；不要删除登记表后再更改地图，否则无法保证跨地图版本的旧编号。仅重新生成相同地图、切换场景或改变原图字典顺序不会改变编号。

这些数据方便之后转换 STM32 地图表，本轮没有生成固件或改动 STM32 工程。

## 当前结果与验证

本次按种子 7、默认速度生成七个场景各一局，共七局。前六个场景顺序保留，第七个改为定点藏匿转移，不再使用警方较慢对照。

| 场景 | 持续时间 | 结果 |
| --- | ---: | --- |
| 两格藏身智能 | 180.0 秒 | 小偷胜 |
| 三格藏身智能 | 180.0 秒 | 小偷胜 |
| 两格藏身预设 | 180.0 秒 | 小偷胜 |
| 三格藏身预设 | 180.0 秒 | 小偷胜 |
| 两格连续逃跑 | 40.1 秒 | 警方胜 |
| 两格警方快 20% 连续逃跑 | 11.9 秒 | 警方胜 |
| 两格定点藏匿转移 | 180.0 秒 | 小偷胜 |

这不是胜率估计，也没有证明新定点策略优于原藏身策略。本次七局为警方两胜、小偷五胜；双方路线均有变化，不代表整体搜索能力已经最优。未做多随机种子胜率评估。

100 项离线测试通过，覆盖连续二维接触、追踪记忆、信息隔离、后退方向、两处错误转向复现、停靠直到检测、真实路口藏点、多出口、空死路跳过、搜索覆盖，以及标注稳定性、原边唯一覆盖、长度、方向和所有节点对距离保持。

`qa/refuge-labels-audit.json` 另外核对七局的实际输出：接触后继续运动的非终局采样帧为 0；警方检出后返回初始取宝模式为 0；五秒内 A→B→A→B 的采样节点往返为 0；全部停靠点合规，全部逃跑计划沿原图合法边且无重复节点。采样核查不替代连续碰撞测试，也不保证所有未来参数下都无折返。

实际浏览器检查：节点和路段点击、两个开关、宝藏定位说明、切换场景后编号、抓捕终局、JSON 实际下载及内容一致、1100×1000 桌面和 390×844 手机布局均通过；本轮未出现页面脚本错误。手机页面未整体横向溢出，地图单独滚动。临时浏览器尺寸已恢复。截图见 `qa/annotations-desktop.jpg` 和 `qa/annotations-mobile.jpg`。

## 前期藏点与标注改动清单（历史记录）

以下路径均相对于本目录。原始地图、路线规划器和 STM32 工程未修改；历史回放快照未重写。

| 状态 | 文件 | 内容 |
| --- | --- | --- |
| 修改 | `simulate.py` | 持续路线、真实藏点、藏点转移场景、警方三格检测和覆盖搜索、生成地图标注 |
| 修改 | `config.json` | 独立警方检测距离、紧急重规划阈值 |
| 修改 | `test_simulate.py` | 原有停靠与路线测试适配真实路口、多出口和有限路线卡 |
| 修改 | `replay.template.html` | 标注控件、详情、图例、手机布局及当前策略说明 |
| 修改 | `README.md` | 当前行为、使用、验证与完整清单 |
| 修改 / 重新生成 | `report.json`、`escape_routes.json`、`replay.html` | 七局新结果、路线卡及独立回放 |
| 新增 | `map_annotations.py` | 稳定节点与路段导出、原图对应关系 |
| 新增 | `map_annotations.js` | 独立标注显示与点击交互 |
| 新增 / 生成 | `map_annotations.json` | 可用于后续转换的地图数据 |
| 新增 | `test_annotations.py`、`test_refuge.py` | 标注与新策略回归测试 |
| 新增 / QA | `qa/verify_annotations.cjs`、`qa/refuge-labels-audit.json` | 当前输出静态核查及结果 |
| 新增 / QA | `qa/annotations-desktop.jpg`、`qa/annotations-mobile.jpg` | 本轮浏览器截图 |
| 新增 / QA | `qa/refuge-labels-diff.txt` | 相对本轮修改前快照的逐文件差异统计 |
| 新增 / 备份 | `qa/before_refuge_labels/simulate.py`、`config.json`、`test_simulate.py`、`replay.template.html`、`README.md`、`report.json`、`escape_routes.json`、`verify_replay.cjs` | 八份修改前快照，均位于同一备份目录 |

共修改 8 个正式文件，新增 5 个正式文件，另新增以上 QA 产物和快照。旧 `qa/verify_replay.cjs` 保留历史语义，本轮应运行 `qa/verify_annotations.cjs`。`qa` 受既有忽略规则排除。`Tools/` 当前尚未被 Git 跟踪，常规 `git diff` 不显示本工具的逐行变化；差异统计用 `git diff --no-index` 对照本轮快照。没有执行暂存、提交或推送；仓库原有 STM32 修改未处理。

## 后续显示调整：默认可见节点

已核对所附 `.doc` 的场地图和说明：场地 3.6×3 米，相邻黑线中心间距 0.3 米，寻迹黑线宽 25 mm；警方左下出发、小偷右中出发、宝藏在顶部。文档地图与当前连接关系一致，未重描道路或改动策略。

此次将节点图形、N001～N088 编号及图例默认开启，路段信息仍可单独开启。浏览器重新加载验证：88 个节点、88 个编号均已生成，无需先勾选开关。

本次修改文件：`replay.template.html`（默认勾选及提示文字）、`map_annotations.js`（初始化时同步图例和标注宽度）、`replay.html`（重新生成）、`README.md`（说明）。新增 `qa/rules-map-reference.png`（从文档提取的原图）、`qa/nodes-default.jpg`（默认显示截图）。差异摘要：页面模板两处调整、初始化两行替换原一行；仿真结果、地图编号、连接关系和策略均未改动。未修改 STM32，未暂存、提交或推送。

## 前次警方调整：按完整巡查段扫描（历史记录）

警方搜索现在同时比较观察点与至少四格的长直道扫描路线，按可新增覆盖位置、概率权重、行驶和转向耗时、重复道路成本评分，长直道增加 25% 的连续扫描偏好。中央通道从 N006 到 N085（x=6，长度 2.7 米）作为可选完整扫描通道，穿过 T 型和十字路口也不自动截断。并非每次都强制走中央线：已经充分覆盖、其余支路更值得检查时会选择其他路线；从通道中部开始则扫描剩余方向到末端。

一旦选定路线，不因当前未检出、途中的覆盖变化或旧观察点计时过期而取消。检出小偷立即优先追踪，未完成巡查序列保留；丢失后先到最后位置，沿最近方向追查至下一路口，无新线索则恢复剩余巡查。追击中按顺序经过的待巡查节点也算已到达，避免恢复时无故倒回刚经过的节点。当前动作仍遵守原有物理执行时间。

覆盖确认只按实际传感器位置进行，不预先把计划经过的整条路算作已检测。连续三次阴性观测才计入覆盖，离开检测范围或实际检出目标会打断相应阴性计数。已经覆盖的位置仍保留一轮搜索记录，完整扫完再重新开始。强制侧向检出后的死路核查仍保留；普通无目标搜索不再被临时就近死路任务打断，未覆盖死路由统一覆盖评分安排。

新增五项回归测试：中央直道完整扫描、覆盖变化不取消任务、检出打断及线索过期恢复、最后线索到下一路口后恢复、观测不连续不能提前记为覆盖，以及不使用未检测的对手真值（部分测试同时检查多个条件）。共 95 项测试通过，七局输出静态核查通过。页面实际确认巡查说明及起止节点编号可见，无脚本错误；节点编号仍默认开启。只完成离线仿真验证，未执行固件编译或硬件验证。

本轮修改 `simulate.py`、`replay.template.html`、`README.md`、`report.json`、`replay.html`；新增 `test_patrol.py`。QA 更新 `qa/refuge-labels-audit.json`；新增 `qa/police-patrol.jpg`、`qa/patrol-diff.txt`，以及 `qa/before_patrol_segments/` 内 `simulate.py`、`replay.template.html`、`README.md`、`report.json` 四份修改前快照。道路、标注编号、小偷策略与 STM32 工程未改动，未暂存、提交或推送。逐文件差异统计见 `qa/patrol-diff.txt`。

## 本次修正：单出口环路与丢失目标后折返（2026-10-04）

截图中的 N008、N009、N018、N019、N028 这一圈只有 N027 通向外部。原算法把圈内两个行驶方向误当作两条逃生出口。现在从现有图识别只有一个外部入口、内部无分岔的环路，排除其内部藏点；N027 也不作为藏点，因为去掉圈内方向后只剩一条外部退路。预设路线卡随候选藏点重新生成。道路和节点编号不变。

警方实际检出圈内目标且自身在圈外时，用检测位置比较双方到出口的最快时间（包括警方转向成本，并保守修正检测点距网格节点的偏移）。能够抢先或同时到口才改去堵出口；来不及则继续追踪。到口短时守候，满 2 秒后的决策释放堵口任务，4 秒内不重复同一堵口；最后检出超过 12 秒或新检测表明目标已离开、已赶不及堵截时取消。只使用有限观测，不能读取未检测对手真值。堵口行为由定点测试验证，本次七局不代表已演示成功堵口抓捕。

长直道折返来自两处：追踪仍指向已经越过的旧检出坐标，恢复巡查仍指向当前身后的旧队列节点。现在沿最后方向检查到直道末端，越过旧坐标后不再回追旧坐标；从巡查路线中部接入时继续前方剩余路线，跳过的点不会自动记为已探测，之后仍可补查。新检出、线索过期或直道检查结束仍可能合理换向，并非禁止警方掉头。该行为替代上节历史记录中的“到下一路口恢复”。

验证：完整 100 项测试通过，堵口条件最后补充后再次通过 5 项针对性测试；七局重新生成并通过输出核查，全部实际藏点避开该单出口环路，原地图及标注数据与修改前一致。浏览器确认新结果、节点编号和 N027 连接详情正常，无页面脚本错误，截图为 `qa/pocket-fix.jpg`。仅完成离线仿真验证，未执行固件编译，尚未完成硬件验证。

### 本次完整文件清单

以下路径相对于本目录，前面的清单为前期历史记录。

| 状态 | 文件 | 内容 |
| --- | --- | --- |
| 修改 | `simulate.py` | 单出口环路识别、藏点排除、有限观测堵口、沿直道追查及巡查衔接 |
| 修改 | `test_patrol.py` | 丢失目标追查终点改为直道末端 |
| 修改 | `test_simulate.py` | 预设路线出口检查排除主动进入封闭环路 |
| 修改 | `replay.template.html` | 当前策略说明和堵口目标提示 |
| 修改 | `README.md` | 当前结果、行为边界及本次清单 |
| 重新生成 | `report.json`、`replay.html`、`escape_routes.json` | 七局新结果、回放及安全藏点路线卡 |
| 新增 | `test_pockets.py` | 5 项针对环路、堵口、旧坐标和巡查接入的测试 |
| 更新 QA | `qa/refuge-labels-audit.json` | 七局输出检查 |
| 新增 QA | `qa/pocket-fix.jpg`、`qa/pocket-diff.txt` | 浏览器截图及差异统计 |
| 新增快照 | `qa/before_pocket_fix/simulate.py`、`qa/before_pocket_fix/replay.template.html`、`qa/before_pocket_fix/README.md`、`qa/before_pocket_fix/report.json`、`qa/before_pocket_fix/test_simulate.py` | 五份修改前快照 |

正式文件共修改/生成 8 个，新增 1 个。`Tools/` 尚未跟踪，差异使用 `git diff --no-index` 与以上快照比较；`test_patrol.py` 和路线卡没有本次修改前独立快照，不提供虚构的差异行数。未修改 STM32 工程，未执行暂存、提交或推送。

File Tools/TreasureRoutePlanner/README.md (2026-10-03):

# 密室夺宝离线路径规划工具

按用户提供的地图与 2026 规则建立黑线道路图，使用 Dijkstra 计算双方最短距离和带转弯代价的最小时间路线。警方最短为 5.25 m、七次转弯，小偷最短为 3.15 m、四次转弯。距离按 0.30 m 网格推算，实车时间需输入测量参数。

详细路线、算法、警方拦截及小偷逃跑建议见 [策略说明.md](策略说明.md)。本目录为独立离线工具，不控制机器人。

## 使用

需要 Python 3，`planner.py` 和测试只使用标准库，不需额外安装。以下命令在本目录运行：

```powershell
python planner.py --start P --target T --mode distance
python planner.py --start B --target T --mode time --speed 0.35 --turn90 0.60 --uturn 1.20
python planner.py --start P --target T --mode time --speed 0.35 --turn90 1.00
python planner.py --start P --target T --blocked '(6,3)'
python planner.py --start '(6,7)' --target T --heading N --mode time
python planner.py --report results.json
python -m unittest discover -s . -p 'test_*.py' -v
```

`P/police`、`B/thief`、`T/treasure` 是起点与目标别名；也可传入 `(x,y)` 节点。`--speed` 为 m/s，`--turn90` 和 `--uturn` 为相较直行模型额外增加的秒数；默认起始朝向为警方 N、小偷 W，可用 `--heading` 覆盖。`--blocked` 用于静态禁入节点，不自动估计移动对手或车辆尺寸。

重新生成 PNG 需要 Pillow：`python build_visuals.py`。本次使用 Codex 自带 Python 和 Pillow，未安装全局依赖。

## 输出字段

- `nodes/xy`：完整采样节点路径，不等于实际路口计数。
- `legs`：同方向合并后的直行段和段起点转向。
- `navigation_events`：岔路、转弯及预期全局出口方向。
- `estimated_seconds`：输入参数下的行驶时间，不含取宝及确认。
- `shortest_alternatives`：等长最短路；通用接口最多返回 20 条，当前地图的小偷三条全部返回。
- `cycles`：明确列出的四条候选回路，没有声称枚举全部简单回路。
- `structure`：终点、割点、桥与环路秩；不能把普通交汇点当成必经割点。

## 文件清单和变更范围

本次全部新增文件如下，未修改已有仓库文件：

| 文件 | 用途 |
| --- | --- |
| `.gitignore` | 忽略本工具 Python 缓存及 QA 临时文件 |
| `map.json` | 人工描图的线段、网格、起点、端帽和候选回路 |
| `planner.py` | 标准库最短路、朝向时间代价、等长路线枚举及图结构分析 |
| `test_planner.py` | 八项离线算法测试 |
| `results.json` | 已计算的节点边表、双方路线、指令、回路与参数 |
| `build_visuals.py` | 根据建图数据生成 PNG 和 SVG |
| `reference_map.png` | 用户原始地图截图副本 |
| `route_paths.png` | 双方取宝路线图，红色选用小偷上侧等长路线 |
| `escape_cycles.png` | 小偷取宝后的两条候选回路示意图 |
| `map_graph.svg` | 可编辑节点拓扑图 |
| `策略说明.md` | 规则、计算结果、双方策略、执行边界及验证记录 |
| `README.md` | 使用说明及完整变更清单 |

变更摘要：新增 `Tools/TreasureRoutePlanner/` 下上述十二个文件。所有既有 STM32 工程、历史阶段和当前基线文档保持原状。未执行 `git add`、`git commit` 或 `git push`。因为新增文件尚未暂存，普通 `git diff` 不包含这些文件，可用 `git status --short --untracked-files=all -- Tools/TreasureRoutePlanner` 查看完整新增范围。

实测边长、转弯额外耗时、取宝耗时、终点端帽含义和实际黑线连通情况待在调试地图上确认。当前证明限于离线图模型；没有进行 STM32 编译或实车测试。

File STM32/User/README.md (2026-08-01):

# User

用户程序入口目录。

| 文件 | 用途 |
|---|---|
| `main.c` | 初始化各模块并执行主循环调度 |

> CubeMX 生成工程后，应保留其用户代码区，并根据实际外设接入各模块。

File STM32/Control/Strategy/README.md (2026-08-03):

# Strategy

根据比赛规则、机器人状态和传感器信息选择动作。

`灰度/ToF 候选数据（普通红外备用） → 状态判断 → 路线指令 → 电机与声光动作`

待正式规则确认后，再定义抓捕、避让、寻宝和任务优先级。

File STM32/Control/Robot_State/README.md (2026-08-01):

# Robot_State

管理机器人运行状态，暂不实现具体状态机。

```text
待机 → 启动 → 循迹/导航 → 宝藏区域 → 声光提示 → 继续或结束
```

建议状态：`IDLE`、`TRACKING`、`TREASURE`、`AVOIDING`、`FINISHED`、`ERROR`。

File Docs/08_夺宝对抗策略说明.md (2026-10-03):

# 夺宝对抗策略说明：小偷与警察

本文用自然语言说明当前电脑仿真中的策略，供讨论比赛思路和后续移植使用。依据为 `Tools/TreasurePursuitSimulator/simulate.py`、`config.json` 及配套说明，整理日期为 2026-10-04。

## 一、双方共同遵守的前提

- 双方提前保存地图，可以利用道路连接、路口位置和路段长度规划路线。知道地图不等于知道对方在哪里。
- 决策使用自身位置、有限范围内的检测结果、最近检测记录和地图先验。回放显示双方位置只是为了复盘，不代表小车拥有全局观测。
- 当前仿真假设自身位置已知，检测范围内的对方位置能够测得。实际红外传感器能否提供这样的信息、能否确认目标就是对方小车，仍需另外验证。
- 选择路线时同时计算直行和转向耗时，不只比较路程。90°转弯与前后退换向目前都设为 0.5 秒；后退不等于车身旋转 180°。
- 经过宝藏中心即可取宝，不减速、不停车。
- “立即追踪”或“立即逃跑”表示检测后立即改变决策优先级。已经开始的转向需要完成，沿线行驶通常到下一地图节点再执行新路线。

| 参数 | 当前仿真设置 |
| --- | --- |
| 常规双方直行速度 | 都为 1.95 米/秒 |
| 警方较快对照 | 警方为小偷速度的 1.2 倍 |
| 警方检测距离 | 所有当前场景均为三格，即 0.9 米 |
| 小偷检测距离 | 按场景为两格或三格，即 0.6 或 0.9 米 |
| 检测模型 | 四方向窄角检测，每 20 毫秒检测一次，设有 5% 漏检概率 |
| 接触判定 | 双方中心距离达到 0.18 米以内即判抓捕 |
| 比赛时限 | 180 秒 |

这些数值是当前模型参数，不是实车测量结论。道路长度沿用地图的 0.3 米格距，尚未实地标定。

## 二、小偷策略

### 1. 开局先取宝，遇到警方先避险

正常情况下，从出生点选择预计耗时最短的路线赶到宝藏。若途中检测到警方，逃避优先，不为了坚持取宝路线而继续迎面接近。威胁解除后再继续任务。

### 2. 取宝后选择有退路的藏点

藏点放在地图中真实存在的拐角或路口，不放在普通直道路段中间。选择时综合考虑以下条件：

- 不在死路中停靠，也不选择只有一个口连接外界的封闭环路。
- 所在整条直道跨度不超过三格，避免在长直道上等待高速接近的警方。
- 至少保留两个合适的环路方向，且不能把进入单出口封闭环路的方向当成可靠退路。
- 尽量远离警方预计的取宝来路，优先考虑需要警方绕行或多次转弯才能探测到的位置。
- 附近分岔较多，方便转移到下一个藏点；同时考虑到达该点的时间和沿途风险。
- 降低反复经过旧路线、频繁回到刚暴露藏点的倾向。

例如，右上角 N008、N009、N018、N019、N028 组成的一圈，只有 N027 通向外部。圈内虽然能向两个方向走，最后仍必须经过同一个出口，所以这些内部节点不再作为藏点；N027 本身也不作为藏点。

这里的“最佳藏点”是当前信息下评分较好的候选点，尚未证明是全局最优。没有近期检测时，对警方来路的判断只是地图先验。

### 3. 到藏点后等待，有检测再撤离

到达藏点后，先把朝向准备到有利于离开的方向，再保持停靠。没有检出警方时，不因为回放中警方位置变化而主动离开。

实际检出警方后进入逃跑流程。已经停靠且暴露的藏点暂时禁用 30 秒，避免刚逃走又立即返回。前往藏点途中遇到警方，则先评估当前路线是否仍然安全。

### 4. 逃跑要远离警方的来路，并检查是否会相撞

检测到右侧有警方时，优先考虑向左侧区块转移；其他方向同理。但不能只按左右方向机械转弯，还必须检查道路是否相通、转向是否来得及，以及警方能否更早到达前方交会点。

选择逃跑路线时，先比较近期接触风险，再考虑以下因素：

1. 离开后的前几段是否会靠近警方，或进入警方赶来追自己的通道。
2. 是否向远离警方的区块转移。
3. 下一藏点是否容易被警方直接探测到。
4. 到达下一藏点需要多少时间，途中有没有可用分岔，是否重复刚走过的路线。

允许直接原路后退。如果后退比转弯更安全，就不必为了“向前开”而绕向警方。对方尚未被检测到时，不能保证所有交叉路口都不会发生意外交会。

### 5. 选定路线后连续执行，避免来回犹豫

每次选定一个明确的路口或藏点作为目标，按完整路线前进。不会在每个普通网格点仅因相对检测方向改变，就把整条路线推翻。

只有新的实际检测表明下一段存在紧迫交会危险时，才提前重新规划。当前紧急判断关注约 0.3 秒内的接触风险。到达目标后再进行后续选择，减少同一横线上反复折返。

### 6. 当前几种小偷模式的区别

| 模式 | 自然语言描述 |
| --- | --- |
| 藏身后智能逃跑 | 动态选择合适藏点及到达路线，停靠后检测到警方再撤离 |
| 藏身后预设路线 | 从预先生成的合法路线卡中选择路线，仍会结合当前检测筛选风险，不是无条件执行一条固定死路线 |
| 多路口连续逃跑 | 取宝后持续选择逃跑目标，不以长期停靠等待为主要行为 |
| 定点藏匿与下一藏点转移 | 更重视让警方搜索和转弯所需的时间，到藏点等待，暴露后转往下一藏点 |

“到藏点等待”是行为规则，不保证每次都有长时间停靠机会；警方持续接近时，小偷可能一直处于转移过程。没有可用藏点路线时，策略会退回普通逃跑选择。

## 三、警察策略

### 1. 开局走最快到达宝藏的路线

警方先按包含转弯耗时的最快路线前往宝藏区域，途中持续检测。实际检出小偷后，立即优先处理目标，不继续机械执行取宝路线。

警方不能远程读取“小偷已经拿到宝藏”这一仿真内部状态。是否检查过宝藏、当前看到了什么，才是它切换任务的依据。

### 2. 没有目标时，以有效探测覆盖为主

搜索时优先选择能够检查更多未覆盖位置的路线，尤其重视可能的藏点。比较路线时同时考虑新增探测范围、最近线索、行驶时间、转向时间和重复路段代价。

不要求每条黑线都必须开到，也不禁止必要的重复过路。若在一处就能探测到某条支路，可以利用检测范围减少绕行。完成一轮覆盖后，才开始新一轮搜索。

### 3. 长直道按完整巡查段扫描

中央长直道等连续通道可以作为整段扫描路线。选定后，即使暂时检测不到小偷，也继续扫描到该段末端，不因途经 T 型或十字路口而自动中断。

并非每次都必须走中央通道：如果该区域已经充分检查，其他路线能覆盖更多新位置，就选择其他路线。从长直道中部接入时，可以直接扫描前方剩余部分。

真正检测到小偷时可以中断巡查去追踪，未完成的巡查任务保留。覆盖记录只根据实际检测过程更新，不把计划经过的位置提前算成已检查。

### 4. 检出立即追踪，丢失后沿最后方向查找

有新检测时，向实际检出目标的位置追踪。短暂漏检不会立刻放弃，警方保留最后位置和运动方向作为线索。

如果还没到达最后检出位置，先去那里；如果已经沿目标方向越过旧位置，就不再回头追旧坐标。随后沿最后方向检查到直道末端，无新线索再恢复搜索；线索超过 12 秒也会失效。

恢复旧巡查时，从当前接入位置继续前方剩余路线，不为了补旧队列中的节点而无故倒回。跳过但没有实际检测到的区域仍保留为未覆盖，后续可以补查。新检出、线索到期或路段检查结束时，仍可能合理换向。

### 5. 小偷在单出口环路内时，优先判断能否堵口

当实际检测确认小偷位于上述单出口环路内部，而警方在圈外时，先找出它通向外部的唯一出口。

比较警方赶到出口的时间与小偷最快逃到出口的时间。如果警方能够抢先或同时到达，就直接前往出口堵截；赶不及则继续正常追踪。这个判断使用检测到的位置和地图，不能使用尚未检测到的小偷真实位置。

例如，小偷在右上角那一圈被检出时，警方可把 N027 作为堵截目标。到口后短时守候，满 2 秒后的决策释放堵口任务，随后 4 秒内不重复同一堵口。若新检测表明小偷已经离开、已来不及堵截，或旧线索超时，则取消堵口，避免长期守空口。

当前实现针对“只有一个外部入口、内部无分岔的环路”，没有声称能处理所有复杂封闭区域。堵口也不等于必然抓获。

### 6. 死路要有选择地检查

若完整死路支路及其中间位置都在检测范围内，连续三次未检出后可记为已查，不必再开进去。若覆盖不完整，就不能仅凭入口处没看见车，认定整条死路为空。

新的侧向检测指向死路时，应优先返回核查。普通没有线索的死路纳入整体覆盖搜索，避免不断插入临时绕行任务而破坏完整巡查。

### 7. 接触后立即结束比赛

仿真按双方连续运动中的二维距离判断抓捕，包括交叉路口交会、原地停靠和检测盲区。是否抓到由接触条件决定，不要求警方或小偷先识别到对方。

## 四、使用边界与后续落地

以上描述对应当前离线程序，不代表实车已经具备同等定位、测距和目标识别能力。当前尚未完整模拟制动与加速、车身旋转包络、循迹偏差、定位误差、掉宝及取宝机构。

路线和藏点采用启发式选择，单组回放不能证明胜率或全局最优。双方检测不到的信息不会因为地图已经烧入芯片而自动获得。

后续移植需要把策略输出的“下一节点、行进方向、停靠或追踪目标”交给实际循迹和底盘控制，并验证路口识别、位置更新、传感器覆盖和真实动作耗时。本次仅整理文档，没有修改策略代码、STM32 工程或执行固件编译。

验证状态应按实际工作区分：本策略目前完成的是离线仿真测试，尚未完成硬件验证；后续若固件仅完成编译，应记录为“仅编译通过，尚未完成硬件验证”，不能把该表述当作本次已编译的结论。

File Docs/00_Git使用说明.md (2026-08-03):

# Robot_Treasure Git 使用说明

本文面向第一次接触 Git 的项目成员。看完后，你应该能够完成日常代码提交与同步。

## 1. Git 是什么

Git 是一个代码版本管理工具，可以记录每次修改，方便团队成员协作，也能在出现问题时查找历史版本。

## 2. Git 在本项目中的作用

|作用|说明|
|-|-|
|记录修改|保存 Robot_Treasure 项目每次有意义的代码变化|
|团队同步|把自己的代码分享给队友，并获取队友的最新代码|
|查看历史|了解某个功能何时修改、修改了什么|
|减少丢失|代码上传到 GitHub 后，不只保存在个人电脑中|

## 3. 本地 Git 仓库与 GitHub

|位置|作用|
|-|-|
|本地 Git 仓库|位于自己的电脑中，用于修改、检查和提交代码|
|GitHub 远程仓库|位于网络上，用于保存和共享团队代码|

两者不会自动保持一致，需要手动同步：

本地提交 → `git push` → GitHub

GitHub 最新代码 → `git pull` → 本地仓库

> `git commit` 只保存到本地仓库；执行 `git push` 后，提交才会上传到 GitHub。

## 4. 日常开发流程

开始开发前，建议先获取团队最新代码：

`git pull`

然后按照以下顺序操作：

修改代码

↓

`git status` 查看修改

↓

`git add 文件名` 添加指定文件，或使用 `git add .` 添加当前目录中的全部修改

↓

`git status` 再次确认准备提交的内容

↓

`git commit -m "提交说明"` 保存本地版本

↓

`git push` 上传到 GitHub

提交说明应简短、明确，例如：

```bash
git commit -m "完成电机驱动"
```

## 5. 常用 Git 命令

请在 Robot_Treasure 项目根目录打开终端并执行命令。

|命令|作用|完整示例|
|-|-|-|
|`git status`|查看文件修改和暂存状态|`git status`|
|`git add 文件名`|把指定文件添加到暂存区|`git add Core/Src/main.c`|
|`git add .`|把当前目录中的全部修改添加到暂存区|`git add .`|
|`git commit -m "提交说明"`|把暂存区内容保存为本地版本|`git commit -m "完成电机驱动"`|
|`git push`|把本地提交上传到 GitHub|`git push`|
|`git pull`|从 GitHub 获取并合并最新代码|`git pull`|
|`git log --oneline`|简要查看提交历史|`git log --oneline`|

> 使用 `git add .` 前要先执行 `git status`，确认没有把无关修改加入提交。

## 6. 使用 VS Code 图形化操作

不熟悉终端时，可以使用 VS Code 左侧的“源代码管理”功能：

修改文件

↓

打开“源代码管理”

↓

检查更改，并暂存需要提交的文件

↓

填写提交信息

↓

点击“提交”

↓

点击“同步更改”

“提交”相当于保存到本地 Git 仓库；“同步更改”会与 GitHub 同步。在点击前应确认网络正常，并留意 VS Code 的提示。

## 7. 团队协作

团队代码同步的基本过程：

队友修改代码

↓

队友执行 `git push` 上传到 GitHub

↓

其他成员执行 `git pull` 获取最新版本

建议每天开始开发前执行一次：

```bash
git pull
```

如果 `git pull` 提示冲突，不要随意删除代码。先停止提交，和修改同一文件的队友一起确认应该保留哪些内容。

## 8. 注意事项

不要提交以下文件：

|文件类型|示例或说明|
|-|-|
|Keil 编译生成文件|`Objects/`、`Listings/`、`Output/`、`Debug/`|
|HEX 固件文件|`*.hex`|
|AXF 调试文件|`*.axf`|
|临时或备份文件|`*.tmp`、`*.bak`|

这些文件已经通过项目根目录的 `.gitignore` 自动过滤，通常不会被 Git 添加。

每次提交前仍应执行：

```bash
git status
```

确认提交内容只包含本次需要共享的代码和文档。

多人协作、功能分支和 Pull Request 操作，请阅读：[07_团队协作与Git分支说明.md](07_团队协作与Git分支说明.md)。

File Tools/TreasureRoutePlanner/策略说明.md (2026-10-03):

# 密室夺宝地图建图和比赛策略

已按提供的地图建立黑线无向图，并计算双方取宝路线。按每格 0.30 m 推算，警方的唯一最短距离路线为 5.25 m，小偷有三条 3.15 m 的等长路线，其中两条只需四次直角转弯。警方另有 5.85 m、五次转弯的路线，转弯较慢时应选这条。小偷取宝后优先考虑有多个出口的回路，并根据警方位置重新选路；固定绕圈不能保证不被抓捕。

本文的“最短”指已建图模型中的最短距离；“最快”指给定运动参数后的模型最小时间。比赛胜率还受循迹稳定性、取宝成功率、感知范围、对手动作及裁判判定影响，不能由静态最短路直接证明。

## 1 规则依据和规划边界

主要依据为用户提供的《202密室夺宝 王善华 18951962935.doc》，正文标为 2026 江苏省大学生机器人大赛比赛规则；地图来源为同次提供的截图。原始文件位于 `D:/xwechat_files/wxid_72iw48divpya22_7671/msg/file/2026-10/202密室夺宝 王善华 18951962935.doc`。

| 与策略有关的规则 | 对规划的影响 |
| --- | --- |
| 每局三分钟，警方在左下蓝区，小偷在右中红区出发 | 两套起点和两套任务状态；保留本局计时 |
| 机器人必须沿 25 mm 黑线循迹 | 黑线是道路，白色区域不能作为捷径；这不是把黑线当墙的迷宫 |
| 场地 3.6 m × 3 m，相邻黑线中心距 0.3 m | 可用格数计算距离；米制值仍需现场核对 |
| 取到铁块才允许发出声光提示，持有期间持续提示 | 到达 T 不等于取宝成功，必须依赖真实获取检测 |
| 警方先取宝获胜；小偷先取宝后，警方抓捕并缴得宝藏获胜 | 警方按局面切换抢宝和拦截，小偷取宝后继续逃避抓捕 |
| 双方均未取宝时，警方抓到小偷也可获胜 | 警方可以在取宝前实施有效拦截；小偷从开局就要避开警方 |
| 有效抓捕为同一车道内的车身相碰；相邻车道的擦碰不计 | 距离传感器发现目标不等于抓捕成功；判断同车道的接触风险 |
| 小偷取宝后冲线须还宝、关闭提示、回起点，计时不重置；冲线三次判负 | 稳定循迹比盲目提高速度重要；不能以主动冲线作为逃跑方法 |
| 故意拖延启动、故意冲线和消极比赛可判负；规则另列“小偷取宝后躲在某处不动，但快被抓时故意冲线”的判负情形 | 取宝后可建模藏身警戒及沿线撤离；不能把正常停靠躲藏一概视为违规，也不能用故意出界重置逃避抓捕 |
| 实际地图没有红框和黄色填涂，只有宝藏区文字 | 不能用截图中的黄色区域作为实车宝藏识别条件 |

图上的短横向端帽被当作路线终点标记，不作为额外岔路；连续交叉黑线被当作连通路口。它们都应在调试地图上复核。起点采用出发端帽中心，宝藏中心采用顶部 `(5.5,0)`，起始朝向按警方向上、小偷向左设置；不包含出发区车体中心偏置或取宝机构偏置。

## 2 地图模型

坐标左上为 `(0,0)`，x 向右，y 向下，整数网格共 12 列、10 行。P 为 `(0,9)`，B 为 `(11,5)`，T 为 `(5.5,0)`。T 将一条完整网格边拆成两条半格边，避免把宝藏误放在左右路口。

图包含 **121 个采样节点、139 条无向边、一个连通分量、19 个独立环路、13 个终点**。这里的 19 是图的环路秩 `E − V + 1`，不是全部简单回路的数量；121 也不是传感器应该识别的路口数量，包含直线中间采样点。

`map.json` 保存人工描出的水平及竖直线段；`map_graph.svg` 显示全部节点；`results.json` 保存边表、割点、桥、路线、转弯指令和候选回路。原图保存为 `reference_map.png`。所有线段可单独审查和修改，图与机器人控制工程相互独立。

## 3 双方取宝路线

下表只列行驶方向变化的位置，中间会经过其他路口。不能仅按表里的转弯次数数路口，实际执行应同时使用 `results.json` 中的 `navigation_events`。

### 3.1 警方最短距离路线

`P(0,9) → (0,7) → (3,7) → (3,6) → (5,6) → (5,7) → (6,7) → (6,0) → T(5.5,0)`

| 段 | 行驶方向 | 推算距离 m | 段起点动作 |
| --- | --- | ---: | --- |
| 1 | 上 | 0.60 | 按初始朝向前进 |
| 2 | 右 | 0.90 | 右转 |
| 3 | 上 | 0.30 | 左转 |
| 4 | 右 | 0.60 | 右转 |
| 5 | 下 | 0.30 | 右转 |
| 6 | 右 | 0.30 | 左转 |
| 7 | 上 | 2.10 | 左转，沿中央竖线通过多个路口 |
| 8 | 左 | 0.15 | 左转，向宝藏中心靠近 |

总长度 **17.5 格，即 5.25 m**，七次直角转弯，无掉头。在当前图中，它是唯一最短距离路线。

### 3.2 小偷的两条较少转弯路线

中央路线：

`B(11,5) → (10,5) → (10,3) → (6,3) → (6,0) → T(5.5,0)`

上侧路线，也是 `route_paths.png` 中的红色虚线路线：

`B(11,5) → (10,5) → (10,3) → (8,3) → (8,0) → T(5.5,0)`

| 路线 | 分段方向和推算距离 m | 总长 | 直角转弯 |
| --- | --- | ---: | ---: |
| 中央 | 左 0.30，上 0.60，左 1.20，上 0.90，左 0.15 | 3.15 m | 4 |
| 上侧 | 左 0.30，上 0.60，左 0.60，上 0.90，左 0.75 | 3.15 m | 4 |

两条路线均为 **10.5 格**，按统一直行和转弯参数计算时间相同。上侧路线在到达顶部前绕开中央 `(6,3)`，可在警方正在中央通道上行时作为候选；它并非在所有对手行为下更安全。

第三条等长路线经过 `(8,2) → (6,2)`，需要六次直角转弯。所有等长路线已在 `shortest_alternatives` 中列出，适合被占道后重新选择。

### 3.3 警方少转弯路线

`P(0,9) → (0,7) → (3,7) → (3,9) → (6,9) → (6,0) → T(5.5,0)`

分段为上 0.60、右 0.90、下 0.60、右 0.90、上 2.70、左 0.15 m。总长 **5.85 m**，五次直角转弯，无掉头。相较最短距离路线，多走 0.60 m，少转两次。

## 4 算法和最快时间

距离规划使用 Dijkstra，在相同最短距离中优先减少直角转弯，再减少掉头。边权用整数半格单位，完整一格为 2，半格为 1，避免浮点误差改变最短距离。

时间规划将状态扩展为 `(节点, 朝向)`，否则同一路口从不同方向进入的转弯代价会被错误合并。每次转移计算：

`转移时间 = 边长 / 直行速度 + 直角转弯额外耗时 + 掉头额外耗时`

“转弯额外耗时”是相较直行边权额外增加的时间，包括减速、转向、重新寻线等需要测出的部分；不能把整段含直行的耗时再次加上，以免重复计时。当前模型没有使用弯道不同速度、路口额外停顿、轮胎打滑或随机失败概率。

用 `v = 0.35 m/s`、每次直角转弯额外 `τ = 0.60 s`、掉头额外 `1.20 s` 作为演示参数，得到：

| 路线 | 距离 m | 直角转弯 | 模型行驶时间 s |
| --- | ---: | ---: | ---: |
| 警方最短距离 | 5.25 | 7 | 19.20 |
| 警方少转弯 | 5.85 | 5 | 19.71 |
| 小偷中央或上侧 | 3.15 | 4 | 11.40 |

这些是模型估算，不是现有小车实测时间，不含启动、停车对位、取宝及确认耗时。同等运动参数下，小偷在模型中领先 7.80 s；不能据此断言本队一定获胜。

警方两条路线的时间分别为 `5.25/v + 7τ` 和 `5.85/v + 5τ`。少转弯路线更快的条件为：

`τ > 0.60 / (2v) = 0.30/v`

例如 `v = 0.35 m/s` 时，分界为每次转弯约 **0.857 s**。取 `τ = 1.00 s` 时，时间规划会自动选择 5.85 m 路线，模型时间约 21.71 s，短路线则为 22.00 s。这个阈值只适用于当前两条路线和统一运动代价模型；更复杂的实测边权应重新求解。

取宝争先应比较完整完成时间：`本方最小行驶时间 + 本方取宝确认耗时` 与对手相应时间，并为定位和抓取误差留出余量。提高速度后也要重算，路线不会始终保持不变。

## 5 小偷策略

开局按实测时间参数选择路线；若中央通道存在警方或可靠的占道预测，考虑上侧等长路线。在宝藏附近完成减速对位，获取传感器确认后才开启声光提示，并进入逃跑状态。

取宝后，若警方仍从中央通道下方向上接近，而且左侧出口无目标，初始候选是沿取宝时的向左朝向继续进入左侧大回路。这样无需在 T 原地掉头。不过，警方可以走捷径拦截，所以不能写成无限重复固定回路的脚本。

| 候选回路 | 一圈推算长度 | 直角转弯 | 使用判断 |
| --- | ---: | ---: | --- |
| 顶部小矩形 | 1.20 m | 4 | 空间小，容易被守入口，不作为默认逃跑目标 |
| 中央窄回路 | 3.60 m | 4 | 可连通，但离警方常见取宝通道近，需要确认威胁位置 |
| 左侧大回路 | 9.00 m | 10 | 可从 T 向左进入，作为初始候选；在岔路重算以防被预判 |
| 右侧回路 | 5.40 m | 6 | 位于 `(6,3)` 至右下区域，需要先规划连接路线，不是从 T 出发的一圈 |

左侧大回路为：

`T → (4,0) → (4,1) → (2,1) → (2,2) → (0,2) → (0,4) → (3,4) → (3,9) → (6,9) → (6,0) → T`

候选回路已逐边验证连通且闭合。回路长度不等于安全程度；例如一圈很长但有便捷捷径时，警方仍可能提前到达汇合处。B 起点、右下几个端点及其他只有一条出口的支路都不适合作为主动躲藏目的地。

动态选择可以采用有限时间范围的保守评分：以每个可能的警方位置为起点，计算警方到候选路线各采样点的最早可能时间，再减去小偷到这些点的预计时间；取所有警方位置和采样点中的最小值，优先选择最小时间余量最大的路线。

`安全评分 = min[警方最早到达时间 − 小偷预计到达时间]`

在评分前应剔除同车道迎面接触、同边追及、被封出口及进入无法退避终点的候选；评分后再按较少转弯和稳定行驶选路。需要同时检查边上接触，而不只检查路口到达时间。加入车身长度、有效抓捕距离和观测误差后，余量才具有实际意义；节点评分本身不是安全保证。

每次可信路口定位或目标观测后只执行下一段计划，再重新评估。四方向距离数据通常只能给出目标方位和局部距离，不能直接当成警方全局坐标；无法唯一定位时保留多个可能位置，对它们分别计算并取最不利值。这部分是策略设计，本工具尚未实现实时感知、对手状态估计或追逃控制。

## 6 警方策略

先以本方实测最小完成时间判断能否抢先取宝。警方取到宝藏即可按规则获胜，取宝确认与提示逻辑必须完整。若判断小偷先到，应利用图的连通关系规划拦截，同时保留继续取宝的机会。取宝前已经发生有效抓捕，同样可按规则判警方获胜，不能把抓捕模式限定在小偷取宝之后。

在可靠识别目标路线后，对目标未来路线上的节点及同车道边段预测到达时刻，寻找警方能更早到达的候选拦截位置。在当前路线中，`(6,3)`、`(6,7)`、`(3,7)`、`(6,0)` 是相关汇合路口，实际是否能拦截取决于双方当前位置和时间；它们不是全图必经割点，不能只守一个点并声称能封住所有路线。

预测到目标将进入支路时，可在其唯一出口附近规划接近路线；目标仍有多个出口时，重新估计其选择。对手位置不确定时优先驶向有观测价值且可继续导航的路口，避免没有目标依据就冲进终点支路。判断同车道接触和缴得宝藏仍须服从实际检测与裁判规则，距离阈值不能代替胜负裁定。

## 7 从离线路线到 STM32 的执行方法

本次只增加离线建图、计算和说明，没有改动任何 STM32 测试工程，也没有控制电机。后续集成应单独复制实验工程，复用已经验证的循迹、路口、转向和故障停车模块。

建议任务状态为：等待比赛信号、抢先取宝、取宝对位与确认、小偷逃跑、警方追踪或拦截、比赛结束和故障停车。状态切换必须有实际事件依据，尤其是宝藏检测、可信定位、线外状态及裁判信号。

高层规划输出 `当前位置、目标节点、预计路口出口、下一行驶方向、转向动作、预期边长`；底层循迹和转向模块负责实际执行。不能用“跑固定秒数然后转弯”替代定位，也不能只靠遇到第几个黑色块更新坐标。`navigation_events` 中的路口出口应与灰度识别结果和编码器距离相互核对。

当预期路口形态、行驶距离和观测结果不一致时，应按已验证的恢复与故障逻辑处理，避免错过一个路口后继续盲走。T 周围有文字，需在调试场地验证文字是否影响灰度和路口识别；最后半格的停车位置还需要结合车体中心、灰度探头、吸取机构和铁块位置标定。

声光输出应绑定实际持有状态；取宝失败不能提前开启，持宝期间持续保持，丢宝或按规则还宝重置时关闭。比赛计时不应因普通冲线回起点而重新开始。

## 8 验证情况

已通过八项离线测试：独立半格 BFS 校验最短距离、端帽与断线不产生虚假道路、时间代价路线切换、全部等长最短路、阻塞绕行和不可达处理、回路闭合、转弯计时、非法参数处理。另扫描截图全部 218 条可能的相邻网格连线，检测出的 138 条完整格线段与人工描图一致；拆分宝藏所在边后成为 139 条图边。路线与回路 PNG 已生成并逐图查看。像素核对只能证明截图上的线段几何对应，不能代替现场确认端帽含义、连通规则或实际距离。

以上不代表 STM32 编译、烧录、取宝、对手感知或实车追逃验证。本次未执行这些工作。后续实验工程即使通过 Keil 编译，在实车验证前仍应标记为：**仅编译通过，尚未完成硬件验证**。

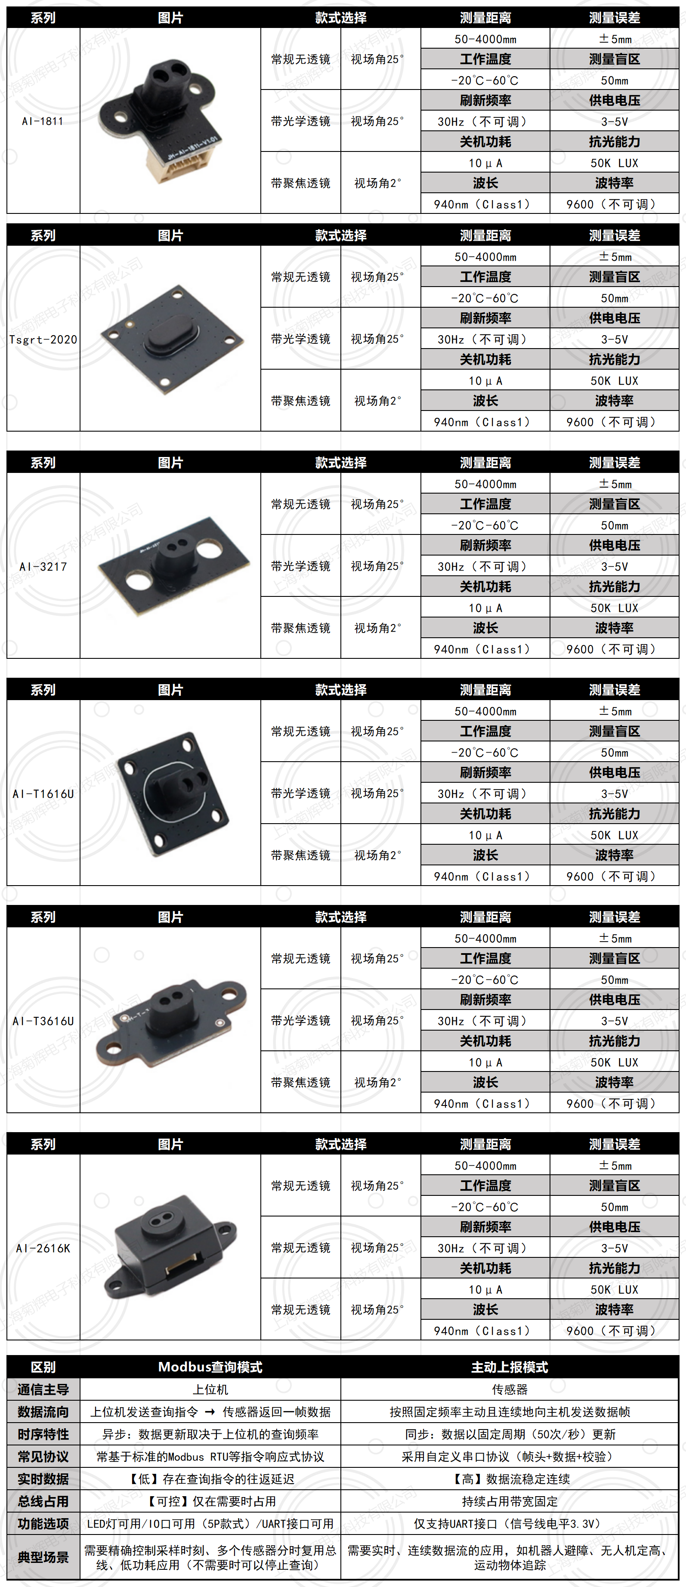
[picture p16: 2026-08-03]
硬件资料（部分已有）/AI-1811/1-TOF产品目录.png

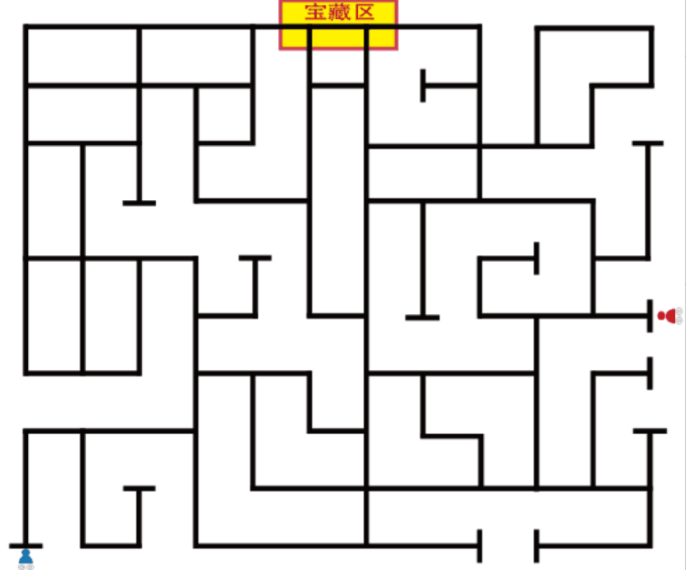
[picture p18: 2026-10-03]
Tools/TreasureRoutePlanner/reference_map.png

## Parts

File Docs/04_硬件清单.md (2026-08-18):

# 04 硬件清单与集成约束

本文是当前已确定硬件架构的技术基线，不是简单采购清单。购买状态与技术选型状态分开记录；未标为“已购买”的项目不得由本文推断为已下单。

## 1. 状态总览

| 状态 | 项目 |
|---|---|
| 已购买 | R5 铝合金四驱底盘、MC520P30_12V 编码器电机 ×4、65 mm 黑色轮胎 ×4、前后黑色 ABS 板 |
| 已购买，单模块基础读取已验证 | AI-1811 ToF 激光测距模块（主动上报、带光学透镜）×1、USB 转 TTL 模块 ×1；USB 转 TTL 用于电脑串口测试，12B 已完成 AI-1811 直接连接 STM32 的基础读取 |
| 技术选型已完成；购买状态须按项目记录确认 | MD240A 四路 TB6612 驱动板、LB326E 12 V 2600 mAh 电池、12.6 V 1.5 A 充电器、3 A 多路 DC-DC、NCHD12 ×2 |
| 实际购买状态仍需项目记录确认 | STM32F103RCT6 开发板、ST-Link V2 |
| 已购/备用/对比测试 | 普通红外传感器 ×4 |
| 功能已确认但规格仍待定 | LED、有源蜂鸣器、MOSFET 或三极管、强力磁铁、总开关、保险丝、连接器、各类支架 |

## 2. 底盘和动力组件

### 2.1 R5 铝合金四驱底盘（已购买）

| 项目 | 参数 |
|---|---|
| 底板 | 2 mm 铝合金 |
| 外形尺寸 | 约 190 mm × 198 mm × 72 mm |
| 商品标注重量 | 约 0.97 kg |
| 转向 | 四轮差速 |
| 动力配置 | 4 电机、37 电机支架 ×4、金属联轴器 ×4 |
| 轮胎 | 65 mm 黑色大摩擦力轮胎 ×4 |

套餐包含铝合金底板 ×1、MC520 编码器电机 ×4、65 mm 轮胎 ×4、37 电机支架 ×4、金属联轴器 ×4、XH2.54 双头排线 ×4、XH2.54 单头排线 ×4、安装工具及固定螺丝。底盘的商品尺寸与重量须在到货后复测。底盘本身约 0.97 kg，因此电池、支架及板卡应低位、轻量、靠近几何中心安装。

### 2.2 MC520P30_12V ×4（已购买）

| 参数 | 数值 |
|---|---|
| 电机类型 | 永磁有刷直流减速电机 |
| 额定电压 / 减速比 | 12 V / 1:30 |
| 空载 / 额定转速 | 360±20 RPM / 290±20 RPM |
| 额定 / 堵转电流 | 0.3 A / 3 A |
| 额定 / 堵转扭矩 | 1.5 kg·cm / 4.5 kg·cm |
| 额定功率 | 约 4 W |
| 编码器 | AB 相正交霍尔，供电 3.3～5 V，磁环 13 线 |
| 商品标注计数 | 1560 / 输出轴一圈 |
| 接口 / 输出轴 / 重量 | XH2.54 6 Pin / 6 mm D 型偏心轴 / 约 150 g |

R5 原厂配套保证了电机、支架、联轴器、轮胎、线束的尺寸配合，四台型号一致且带编码器，因此无需重新加工底盘。13 线 × 30 减速比为 390；AB 相四倍频后为 1560。**1560/圈为商品标注值，收到实物后应通过手动旋转输出轴一圈和 STM32 编码器计数实验进行验证。**不得将其当作未经验证的单通道脉冲数。

65 mm 轮胎下额定理论线速度为 `290 ÷ 60 × π × 0.065 ≈ 0.99 m/s`，空载约 1.23 m/s。该速度对稳定循迹偏快，软件应以 0.3～0.5 m/s 初期目标、PWM 上限、加减速斜坡和四轮速度闭环来解决，不靠更换配套电机解决。

### 2.3 MD240A ×1（技术选型已完成）

| 参数 | 数值 |
|---|---|
| 驱动芯片 / 电机通道 | TB6612FNG / 4 路独立 |
| VM 输入 | 6～15 V |
| 单路连续 / 峰值 | 1.2 A / 3.2 A |
| 逻辑控制 | 3.3～5 V |
| PWM | 0～100 kHz，推荐 10 kHz |
| 接口 | XH2.54 6 Pin |
| 尺寸 / 重量 | 约 68 mm × 58.7 mm / 约 26 g |
| 保护 | 过流、短路、TVS 防护 |

| MD240A 通道 | 电机 |
|---|---|
| 1 | `Motor_FL` 左前 |
| 2 | `Motor_RL` 左后 |
| 3 | `Motor_FR` 右前 |
| 4 | `Motor_RR` 右后 |

单电机额定 0.3 A，相对 1.2 A 连续能力有四倍余量；3 A 堵转电流却接近 3.2 A 峰值。因此驱动板适合正常运行但严禁长时间堵转。必须实现 PWM 缓启动/缓减速、最大 PWM 限制、禁止高速直接反转、编码器堵转检测、立即停机、故障延时恢复和连续故障停车。建议判据为 PWM 超阈值且速度连续 100～300 ms 接近零；阈值由实车确定。

## 3. 电源及安全

| 组件 | 当前方案 | 关联与验收 |
|---|---|---|
| 动力电池 | LB326E 12 V 2600 mAh 3S 锂电池 | 3S 电压匹配 12 V 电机和 MD240A 的 6～15 V VM；固定在车体中心、低位 |
| 充电器 | 12.6 V 1.5 A 配套充电器 | 与 3S 电池体系匹配 |
| 控制电源 | 3 A 多路 DC-DC | 5 V 给 STM32 开发板和 5 V 传感器；3.3 V 给编码器及 3.3 V 模块 |
| 保护附件 | 总开关、保险丝 | 规格待定，安装于电池后、分支前 |

```text
LB326E 3S 锂电池
  └─ 总开关 ─ 保险丝
       ├─ 动力支路 ─ MD240A VM ─ 四台电机
       └─ 控制支路 ─ 3A 多路 DC-DC ─ 5V / 3.3V 模块
```

电机不能由 DC-DC 供电，电池直接接 MD240A 动力输入；板载 3.3 V/5 V 不承担主要控制供电。所有模块共地，禁止两个稳压模块输出直接并联。到货后，在接 STM32 前借用万用表检查极性、满电电压、3.3 V/5 V 输出、空载/负载发热；并检查启动复位和驱动/线缆温升。

## 4. 传感器和提示组件

### 4.1 NCHD12 ×2（技术选型已完成）

| 参数 | 数值 |
|---|---|
| 探头/扩展芯片 | 12 路 / PCA9555 |
| 灵敏度与指示 | 可调；每路独立指示灯；有遮光结构 |
| 最小适配线宽 | 商品标注约 10 mm |
| 长 × 宽 / 探头间距 / 重量 | 约 118.8 mm × 30 mm / 约 9 mm / 约 16.5 g |

前模块用于前进循迹与主要路口判断，后模块用于后退与逃跑模式；二者可联合判断姿态/路口，默认不能分别驱动彼此冲突的循迹 PID。前模块置于前轮轴线前方、后模块置于后轮轴线后方，支架必须支持高度和前后距离调节。

两块 NCHD12 共用同一 I²C：前模块 A2/A1/A0=`0/0/0`，7 位地址 `0x20`；后模块=`0/0/1`，7 位地址 `0x21`。这只占用 SCL/SDA 两个引脚，不使用 24 路灰度 GPIO、第二组 I²C 或 I²C 多路复用器。`0x20`、`0x21` 是驱动保存的 7 位地址；HAL 调用用 `addr7 << 1`，不可把默认 8 位写/读地址 `0x40` / `0x41` 当作 7 位地址。

### 4.2 AI-1811 ToF 激光测距模块（候选主方案，单模块基础读取已验证）

当前购买 1 个 AI-1811，已完成单模块基础 UART 读取；四方向安装和再购买 3 个均未最终确定。模块参数按资料与本次实物验证区分记录如下：

| 参数 | 当前记录 |
|---|---|
| 系列/工作模式 | AI-1811；主动上报模式 |
| 镜头/接口 | 带光学透镜；UART |
| 波特率/刷新频率 | 资料记录：9600，不可调 / 30 Hz，不可调；12B 实物验证：115200、8N1，连续稳定收到固定 8 字节帧；本阶段未做精确刷新率标定 |
| 测量距离/盲区 | 50～4000 mm / 50 mm |
| 标称测量误差/视场角 | ±5 mm / 约 25° |
| 供电/UART 信号电平 | 优先使用 3.3 V / 3.3 V |
| 波长 | 940 nm |
| 价格记录 | 激光测距模块 ￥29.8；USB 转 TTL 模块 ￥1.75 |

USB 转 TTL 用于电脑串口测试；12B 已由 AI-1811 直接连接 STM32 完成基础读取：`V→3.3V`、`G→GND`、`T→PA3/USART2_RX`、`R` 不接，USART2 为 115200、8N1、RX Only。实测帧为 `AA 05 FW_L FW_H DIST_L DIST_H CONF SUM`，`FW`/`DIST` 为小端，`DIST` 单位为 mm，`SUM` 为前 7 字节累加和低 8 位。主动上报模式会连续发送数据；PA2 不分配为 USART2_TX，USART3 PB10/PB11 保持调试口；多个模块的发送端不能直接并联到同一个 STM32 UART_RX，最终四模块通信方式仍须由 CubeMX 资源验证决定。

### 4.3 普通红外、ABS 与附件

普通红外模块 ×4 的历史购买记录保留，当前标注为已购、备用和对比测试，不再作为敌方检测的最终首选方案。12A 已在当前台架条件下完成单路基础读取：`VCC→3.3V`、`GND→GND`、`OUT→PB14`，低电平有效；当前电位器设置下，白色目标和黑色非亮面目标在约 10 cm 处均可稳定触发，连续串口采样未观察到明显抖动。该结果仅支持近距离障碍/物体检测基础验证，不代表最终检测距离，也不代表能够识别 ABS、材质或敌方机器人；最终安装高度、角度、永久引脚分配和整车方案仍待后续确认。前后黑色 ABS 板已购买，但不得遮挡灰度、ToF 镜头或红外探头。

强力磁铁用于吸取铁质宝藏；LED 和有源蜂鸣器用于状态提示。若 MCU 输出能力或电压不匹配，须用待定规格的 MOSFET/三极管级驱动。磁铁吸力、驱动管型号与栅/基极电阻、LED 限流电阻、蜂鸣器电压均在实物选型后确定。

## 5. 机械、电气与线束规格待定项

| 类别 | 仍需确定的规格 | 约束 |
|---|---|---|
| 连接器与线束 | 电池、保险丝、开关、动力线、信号线的额定电流、针数、线径、长度与锁扣 | 动力回路不用普通杜邦线；终端需可靠压接/绝缘/应力释放 |
| 支架 | 灰度、ToF、红外、STM32、电池、驱动/DC-DC、磁铁支架 | 固定牢靠、可调、低位，板卡绝缘隔离；ToF 高度和俯仰角须避免测到地面 |
| 安全件 | 总开关、保险丝额定值 | 依电池、线径、峰值电流及实测确定 |
| 走线 | 动力线与传感器线分区 | MD240A 靠近电机；编码器/I²C/UART 线短；电机线不与灰度/编码器/ToF 线长距离平行 |

所有板卡用尼龙柱、铜柱或绝缘板与 2 mm 铝底板隔离。电池、MD240A、DC-DC 必须牢固固定；STM32放在方便调试的位置，DC-DC 靠近电池输入及 STM32 供电区域。

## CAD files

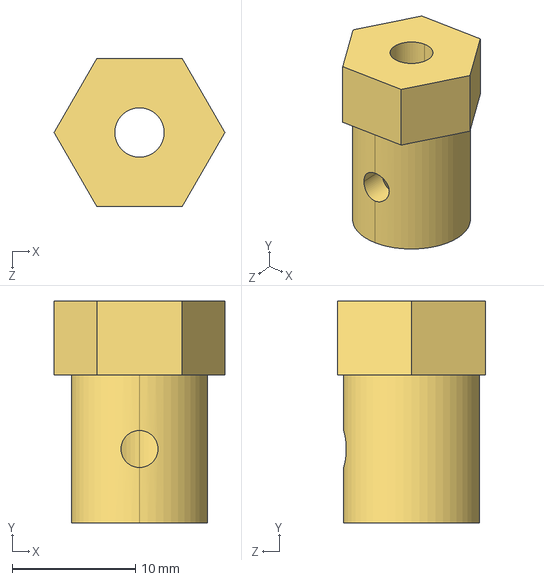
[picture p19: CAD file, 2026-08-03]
硬件资料（部分已有）/R5四驱底盘/3D模型/六角联轴器6mm.STEP
13.9 x 18.0 x 12.0 mm

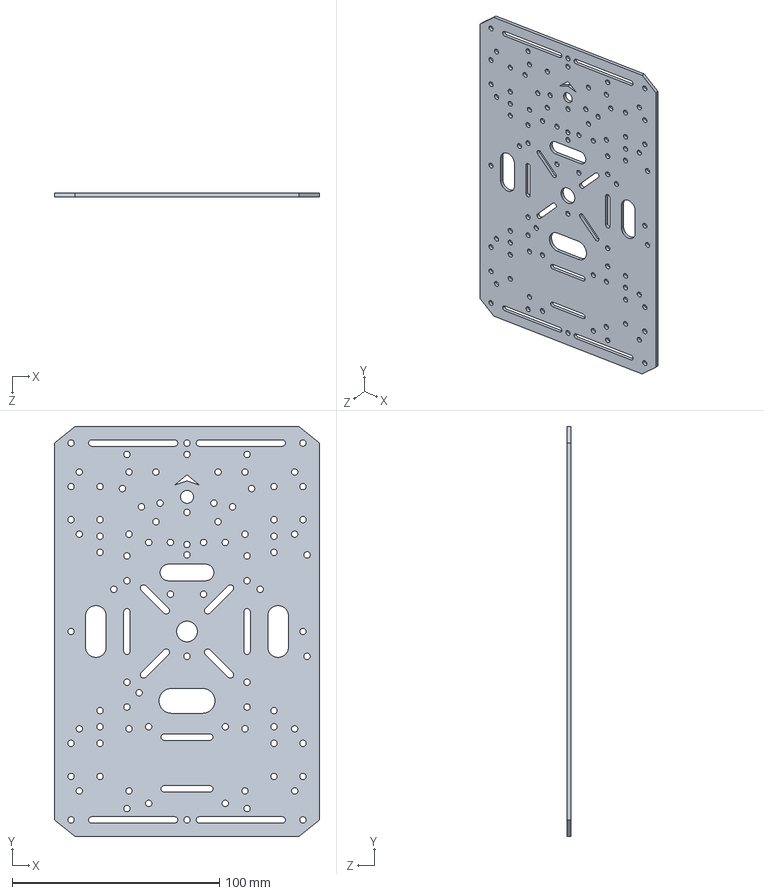
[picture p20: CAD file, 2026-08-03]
硬件资料（部分已有）/R5四驱底盘/3D模型/R5小车底板模型.STEP
128.0 x 198.0 x 2.00 mm

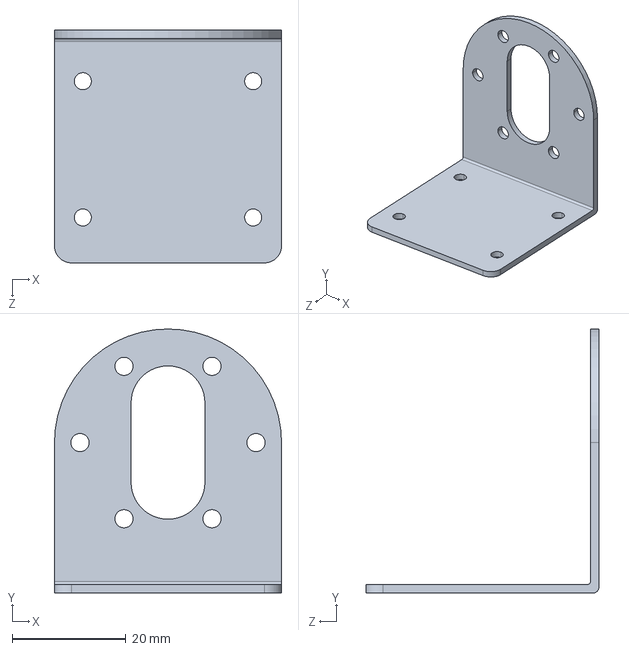
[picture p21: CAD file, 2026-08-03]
硬件资料（部分已有）/R5四驱底盘/3D模型/37电机支架.STEP
40.0 x 46.5 x 41.0 mm

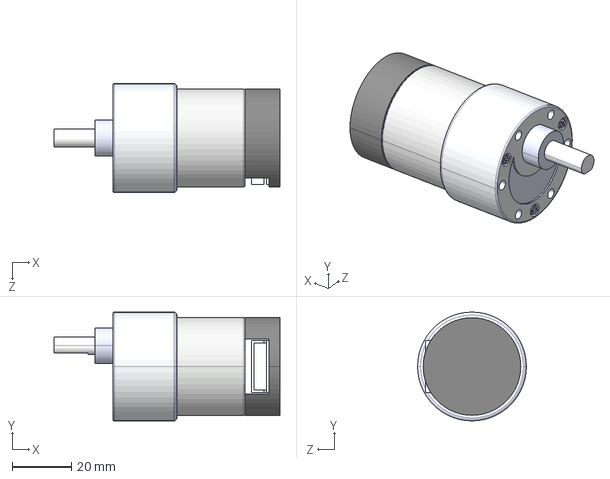
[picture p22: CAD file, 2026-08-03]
硬件资料（部分已有）/R5四驱底盘/3D模型/MC520编码器电机模型.STEP
76.0 x 36.6 x 36.6 mm

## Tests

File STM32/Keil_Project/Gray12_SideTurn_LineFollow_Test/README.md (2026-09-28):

# 12 路灰度最外侧双黑转弯循迹试验

本工程独立复制 `Route15B_SmoothFollow_Test`，复用现有 NCHD12 I2C、前后灰度位置、四轮独立速度 PI、循迹 PID 与平顺控制。来自提供的 `TRACE.c`、`TracePid.c`、`LineFollow.c` 的可用思路是二值加权位置、状态驱动的循迹 PD、偏差降速、基准速度斜坡和转向变化率限制；原文件按 6 路 GPIO 和另一套电机接口编写，本工程按现有 12 路硬件接口实现这些逻辑。

## 操作与转弯

- 前灰度 P12 在车左、P1 在车右；后灰度 P1 在车左、P12 在车右。转弯标志只看前灰度。黑色为 1。
- KEY2 仅在前灰度 12 路全黑 `0xFFF` 时起步。当前离开黑区速度为 100 RPM；看到普通有效线后直接进入循迹，不重启四轮速度环。4 秒还未离开则停车报错。
- 循迹中，前灰度最左侧 P11 **与** P12 同时识别黑线时向左转，最右侧 P1 **与** P2 同时识别黑线时向右转。PID 和四轮速度控制仍为 20 ms 周期，另设 5 ms 前灰度路口监测，避免高速时在相邻两个控制采样之间越过窄路口。识别后先以 100 RPM 受控前进 200 ms；进入该阶段时清除四轮速度 PI 积分，避免继续沿用高速输出。200 ms 到时后的第一项动作是 TB6612FNG 短路制动。制动至少保持 80 ms，并用四轮编码器确认连续 2 次均低于约 2 RPM 后才允许转向；800 ms 仍未停稳则保持制动并报错，绝不释放车轮继续运行。制动期间仍以前灰度确认方向，右侧双黑或全黑锁定右转。随后以四轮固定 PWM 500 原地转向，相对 YAW 达到 50.00°后结束。仅前灰度参与转向保底，后灰度不参与。停止原地转向后，当前灰度可循迹时立即恢复 PID，否则以 100 RPM 直行找线；1.2 秒仍找不到线则主动制动并报错。
- 其余有黑线的范围继续用灰度 PID：线在 P5 或 P8 时，将最终差速修正提高到 400%；线触及 P1～P4 或 P9～P12、但未满足最外侧双黑转弯条件时，也用 400%；其余中心位置用 300%。前灰度位置偏差始终进入位置 PID，后灰度有效时只额外形成前后差的航向修正。四轮速度 PI 不变。
- 停转并切回循迹的同一帧就读取后灰度；后灰度有效则立即启用前、后双灰度位置和航向 PID，不再等待 3 帧。后灰度暂时无效时先以前灰度循迹，后续有效后再切入双灰度，避免无效读数控制电机。
- 两次转弯之间要求至少 3 帧有效循迹线，以免同一黑区重复触发。转弯最长 4 秒；运行最长 180 秒。KEY1、WK_UP 或运行中 KEY2 停车。前灰度一次读错、瞬间丢线或宽黑会先主动制动并在 200 ms 内重读，恢复后重新启动速度环；持续异常、真实堵转等故障仍保持制动。
- JY61P 转向轴按实车验证结果使用 YAW：车身左右转动时 YAW 连续变化，显示正负方向与实际一致。UART5 使用 PC12 接模块 RX、PD2 接模块 TX，默认 9600 8N1；接收使用 UART5 中断，避免 TFT/I2C 占用主循环时漏帧。相对角计算可跨越 ±180° 边界。
- TFT 的 YAW 数值按 200 ms 周期（5 Hz）刷新；YAW 变化不再触发整页重画，只更新必要行。状态和路口计数变化仍立即显示，减少软件 SPI 阻塞灰度采样的时间。
- USART3 调试文字使用 1024 字节环形缓冲非阻塞发送；日志拥塞时允许丢弃调试字节，绝不允许日志等待延迟灰度检测、接近控制或主动制动。FOLLOW、LEAVE、转弯和所有异常退出统一使用主动制动，不再通过关闭 STBY 滑行。
- 5 ms 前灰度安全监测除捕获正常转弯外，也会对丢线、无法解释的宽黑和前灰度 I²C 错误立即主动制动；不再因单次异常永久停机。转向中 YAW 短暂过期时同样先制动，600 ms 内恢复新帧则继续完成原目标角。TFT 的 STATE 下方显示最终故障原因。

## 调参位置

| 文件 | 参数 | 控制对象 |
|---|---|---|
| `Control/LineFollowPID.h` | `KP/KI/KD` | 前灰度位置误差；后灰度不会抵消前灰度 P5/P8 的偏差 |
| `Control/LineFollowPID.h` | `KH` | 前后灰度误差之差，即双灰度航向修正 |
| `Algorithm/SpeedPI/WheelSpeedPi.h` | `WHEEL_FL_B_*` | B 电机，左前轮速度 PI |
| 同上 | `WHEEL_FR_A_*` | A 电机，右前轮速度 PI |
| 同上 | `WHEEL_RL_D_*` | D 电机，左后轮速度 PI |
| 同上 | `WHEEL_RR_C_*` | C 电机，右后轮速度 PI |
| `Control/FollowSmoothing.c` | `SMOOTH_*` | 循迹基准速度斜坡、弯道降速和差速变化率 |
| `User/App_LineFollowExperiment.c` | `ROUTE_*` | 起步、左右侧转向触发、P1或P12保底停转、原地转弯速度、YAW目标角、转弯后找线及超时；中心/侧面灰度 PID 修正倍率 |

灰度控制不是每块灰度各一套 PID：前灰度始终负责位置误差；后灰度有效时，前后之差负责航向修正。四轮速度 PI 则各有独立状态和独立增益入口。以下数值以当前源码为准；用户反馈当前循迹版本已能在地图上以不错的速度和准确度运行。

## 当前参数与测试边界

| 设置 | 当前值 | 修改位置 |
|---|---:|---|
| 起步直行目标 | 100 RPM | `ROUTE_LEAVE_START_RPM_X10=1000` |
| 起步初值/斜坡 | 100 RPM | `ROUTE_LEAVE_INITIAL_RPM_X10=1000` / `ROUTE_LEAVE_RAMP_STEP_RPM_X10=10` |
| 循迹直线基准 | 220 RPM | `LINE_FOLLOW_PID_BASE_RPM_X10=2200`；控制周期 20 ms |
| 大偏差时最低循迹基准 | 120 RPM | `SMOOTH_CURVE_MIN_BASE_X10=1200` |
| 中心边缘/普通中心/侧面修正倍率 | 400% / 300% / 400% | `ROUTE_PID_*_GAIN_PCT`，只放缩灰度 PID 差速输出 |
| 转弯后循迹初值 | 100 RPM | `ROUTE_AFTER_TURN_START_RPM_X10=1000` |
| 转弯后直行找线超时 | 1.2 s | `ROUTE_AFTER_TURN_FORWARD_TIMEOUT_MS=1200` |
| 原地转弯四轮统一PWM | 500 | `ROUTE_TURN_EQUAL_PWM=500`；四轮幅值完全相同，左右仅方向相反 |
| 高速路口监测周期 | 5 ms | `ROUTE_JUNCTION_WATCH_PERIOD_MS=5`；只提高前灰度转弯捕获频率，不改变 20 ms PID 周期或直线速度 |
| 前灰度瞬时异常恢复 | 最多 200 ms | `ROUTE_FRONT_RECOVERY_MS=200`；先主动制动，连续 2 次读数恢复后重新启动循迹；持续异常报故障 |
| 识别路口后的受控前进 | 200 ms，100 RPM | `ROUTE_TURN_APPROACH_DELAY_MS=200` / `ROUTE_TURN_APPROACH_RPM_X10=1000`；进入时清除四轮 PI 积分 |
| 识别路口后的主动制动 | 至少80 ms，最长800 ms | `ROUTE_TURN_STOP_MS=80` / `ROUTE_TURN_STOP_MAX_MS=800`；编码器连续2次低于约2 RPM才允许转向 |
| 停车后等待新YAW帧 | 最多500 ms | `ROUTE_TURN_GYRO_WAIT_MS=500`；短暂串口间隔不再直接故障 |
| 转向途中YAW断帧恢复 | 最多600 ms | `ROUTE_GYRO_RECOVERY_MS=600`；先主动制动，收到新帧后继续原目标角 |
| JY61P转向目标 | 50.00° | `ROUTE_TURN_TARGET_ANGLE_X100=5000`；使用实车验证的 YAW |
| 灰度外环 Kp/Ki/Kd/Kh | 0.075 / 0.008 / 0.007 / 0.005 | `Control/LineFollowPID.h`，系数按 x1000 写入 |
| 差速修正每 20 ms 最大变化 | 25 RPM | `Control/FollowSmoothing.c` 中 `SMOOTH_STEER_STEP_RPM_X10=250` |
| B/A/D/C 四轮速度 PI Kp/Ki | 各 0.80 / 0.25 | `Algorithm/SpeedPI/WheelSpeedPi.h`，系数按 x100 写入 |
| 速度 PI 的 PWM 上限 | 800 | `WHEEL_SPEED_PI_PWM_MAX`；硬件定时器周期为 999 |
| 起步/运行 PWM 下限 | 100 / 50 | `WHEEL_SPEED_PI_PWM_START_MIN` / `WHEEL_SPEED_PI_PWM_RUNNING_MIN` |

## 速度与转向流畅度调节

数值名称带 `RPM_X10` 时，代码中的 `1000` 表示 100.0 RPM；角度名称带 `ANGLE_X100` 时，`5000` 表示 50.00°。建议每次只改一项并记录实车结果。

### 行驶速度

| 参数 | 当前值 | 作用与调大后的结果 | 位置 |
|---|---:|---|---|
| `LINE_FOLLOW_PID_BASE_RPM_X10` | 2200 | 正常循迹基准速度，即 220 RPM。调大后直线更快，但必须给轮速 PI 留出左右差速余量 | `Control/LineFollowPID.h` |
| `SMOOTH_CURVE_MIN_BASE_X10` | 1200 | 大偏差/弯道时最低基准速度为 120 RPM。调大后过弯更快但更容易冲出线；调小更稳 | `Control/FollowSmoothing.c` |
| `SMOOTH_BASE_STEP_RPM_X10` | 120 | 每 20 ms 基准速度最多改变 12 RPM。调大则加减速更快、冲击更明显 | `Control/FollowSmoothing.c` |
| `ROUTE_TURN_APPROACH_RPM_X10` | 1000 | 识别路口后的200 ms受控前进速度，即100 RPM | `User/App_LineFollowExperiment.c` |
| `ROUTE_TURN_APPROACH_DELAY_MS` | 200 ms | 路口进入时间；到时立即短路制动 | `User/App_LineFollowExperiment.c` |
| `ROUTE_AFTER_TURN_START_RPM_X10` | 1000 | 转弯结束后以 100 RPM 找线。调大恢复更快，但刚转完更容易再次冲线 | `User/App_LineFollowExperiment.c` |
| `ROUTE_LEAVE_INITIAL_RPM_X10` / `ROUTE_LEAVE_START_RPM_X10` | 1000 / 1000 | 起步和离开起点均为 100 RPM | `User/App_LineFollowExperiment.c` |

### 转向与循迹流畅度

| 参数 | 当前值 | 作用与调大后的结果 | 位置 |
|---|---:|---|---|
| `ROUTE_TURN_EQUAL_PWM` | 500 | 原地转弯时四轮共同的固定 PWM 幅值。调大转得更有力更快，但惯性和过转增加 | `User/App_LineFollowExperiment.c` |
| `ROUTE_TURN_TARGET_ANGLE_X100` | 5000 | 陀螺仪相对转角停止值，当前为 50.00° | `User/App_LineFollowExperiment.c` |
| `ROUTE_TURN_STOP_MS` / `MAX_MS` | 80 / 800 ms | 80 ms只是最短制动时间；四轮未确认停稳时继续制动，800 ms仍未停稳则安全故障 | `User/App_LineFollowExperiment.c` |
| `SMOOTH_STEER_STEP_RPM_X10` | 250 | 每 20 ms 灰度差速修正最多变化 25 RPM | `Control/FollowSmoothing.c` |
| `LINE_FOLLOW_PID_DEFAULT_KP_X1000` | 75 | 灰度位置误差的主要纠偏力度。调大转向响应更强，过大则左右摆动 | `Control/LineFollowPID.h` |
| `LINE_FOLLOW_PID_DEFAULT_KI_X1000` | 8 | 消除持续的单侧偏差。调大可修正长期跑偏，过大易积累并慢性摆动 | `Control/LineFollowPID.h` |
| `LINE_FOLLOW_PID_DEFAULT_KD_X1000` | 7 | 抑制快速变化和过冲。适当调大可减小摆动 | `Control/LineFollowPID.h` |
| `LINE_FOLLOW_PID_DEFAULT_KH_X1000` | 5 | 前后灰度差形成的车身航向修正。调大可更快拉直车身，过大易蛇形摆动 | `Control/LineFollowPID.h` |
| `LINE_FOLLOW_PID_MAX_CORRECTION_RPM_X10` | 500 | 灰度 PID 区域倍率前最大修正为 50 RPM；当前区域倍率可能进一步放大 | `Control/LineFollowPID.h` |
| `ROUTE_PID_CENTER_EDGE_GAIN_PCT` / `CENTER` / `SIDE` | 400 / 300 / 400% | 依次对应 P5/P8、普通中间区、P1～P4/P9～P12 | `User/App_LineFollowExperiment.c` |

### 四个轮子的速度 PI

`Algorithm/SpeedPI/WheelSpeedPi.h` 中 `WHEEL_FL_B_*`、`WHEEL_FR_A_*`、`WHEEL_RL_D_*`、`WHEEL_RR_C_*` 分别是左前 B、右前 A、左后 D、右后 C 电机。每个轮子的 `KP_X100=80`、`KI_X100=25` 控制该轮是否跟上目标 RPM，不是灰度循迹 PID。当前 `WHEEL_SPEED_PI_PWM_MAX=800`，起步/运行 PWM 下限为 100/50。

这里的 PWM 是四轮 PI 每个控制周期计算的输出，不是固定给电机的 PWM。任何配置都不能越过当前 PI PWM 上限 800。串口故障行现在包含故障前状态、YAW帧年龄、有效帧数、校验错误、UART错误和堵转轮号；若仍出现停车，记录完整 `ROUTE_FAULT` 行即可区分堵转、JY61P漏帧或其他状态故障。

用户反馈当前循迹版本已在地图上运行；本次仓库同步仅执行了编译检查，JY61P 重新接线后和四路红外避障尚未在本次验证。

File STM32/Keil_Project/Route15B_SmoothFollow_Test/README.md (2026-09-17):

# Route15B 平顺循迹试验工程

从 `Route15A_TwoRightTurn_Stop_Test` 独立复制。保留原有双灰度、四轮速度 PI、两次右转后停车和故障停车流程；仅在循迹控制输出到车轮目标转速之间加入 `Control/FollowSmoothing.c`。

新增的三个功能在 `FollowSmoothing.c` 顶部各有独立开关：

| 功能 | 当前初始参数 | 作用 |
|---|---:|---|
| 基准速度斜坡 | 每 50 ms 增加 2 RPM | 循迹启动与转弯后恢复时逐步加速 |
| 按偏差降速 | 偏差 100～300 时从 40 降到 30 RPM | 大偏差时降低基础速度 |
| 转向修正变化率限制 | 每 50 ms 最大变化 2 RPM | 限制左右轮差速突变 |

上述参数仅是编译试验的初值，尚无实机调参依据。停止、传感器失效和堵转仍走原工程的立即停车路径；平顺模块只处理有效循迹样本。转弯阶段沿用原工程控制，未加入旧项目的 IMU 圆弧转弯。

建议依次单独验证基准速度斜坡、偏差降速、转向变化率限制，再验证三者组合；记录直线摆动、弯道越线、路口识别与转弯后找线情况。实机前需按现有工程安全流程核对供电和接线，不把本工程的编译结果当成硬件验证。

Keil ARM Compiler 5 全量编译：0 Error(s)、0 Warning(s)。仅编译通过，尚未完成硬件验证。

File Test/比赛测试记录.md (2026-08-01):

# 比赛测试记录

## 基本信息

| 日期 | 场地版本 | 程序版本 | 电池状态 | 测试人员 |
|---|---|---|---|---|
| YYYY-MM-DD | — | — | — | — |

## 整体结果

| 项目 | 结果 | 用时/次数 | 问题 |
|---|---|---|---|
| 完成循迹 | — | — | — |
| 检测敌方 | — | — | — |
| 获取宝藏 | — | — | — |
| LED + 蜂鸣器提示 | — | — | — |
| 完成全流程 | — | — | — |

## 复盘

- 成功部分：
- 失败位置：
- 参数变化：
- 下一轮修改：

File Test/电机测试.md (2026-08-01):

# 电机测试

| 日期 | 电池电压 | 左轮指令 | 右轮指令 | 实际动作 | 问题/调整 |
|---|---:|---:|---:|---|---|
| YYYY-MM-DD | — | — | — | — | — |

## 检查项

- [ ] 四个电机方向一致
- [ ] 左右轮组可独立正反转
- [ ] PWM 调速有效
- [ ] 连续运行无明显过热
- [ ] 停止指令可靠

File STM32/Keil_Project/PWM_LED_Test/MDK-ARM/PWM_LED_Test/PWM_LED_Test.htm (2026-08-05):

# Static Call Graph for image PWM_LED_Test\PWM_LED_Test.axf

#<CALLGRAPH># ARM Linker, 5060528: Last Updated: Wed Aug 05 23:40:59 2026

### Maximum Stack Usage = 160 bytes + Unknown(Functions without stacksize, Cycles, Untraceable Function Pointers)

### Call chain for Maximum Stack Depth:

__rt_entry_main ⇒ main ⇒ MX_TIM1_Init ⇒ HAL_TIM_MspPostInit ⇒ HAL_GPIO_Init

### Functions with no stack information

- __user_initial_stackheap

### Mutually Recursive functions

- ADC1_2_IRQHandler ⇒ ADC1_2_IRQHandler
- BusFault_Handler ⇒ BusFault_Handler
- HardFault_Handler ⇒ HardFault_Handler
- MemManage_Handler ⇒ MemManage_Handler
- NMI_Handler ⇒ NMI_Handler
- UsageFault_Handler ⇒ UsageFault_Handler
- UART_EndRxTransfer ⇒ UART_EndRxTransfer

### Function Pointers

- ADC1_2_IRQHandler from startup_stm32f103xe.o(.text) referenced from startup_stm32f103xe.o(RESET)
- ADC3_IRQHandler from startup_stm32f103xe.o(.text) referenced from startup_stm32f103xe.o(RESET)
- BusFault_Handler from stm32f1xx_it.o(i.BusFault_Handler) referenced from startup_stm32f103xe.o(RESET)
- CAN1_RX1_IRQHandler from startup_stm32f103xe.o(.text) referenced from startup_stm32f103xe.o(RESET)
- CAN1_SCE_IRQHandler from startup_stm32f103xe.o(.text) referenced from startup_stm32f103xe.o(RESET)
- DMA1_Channel1_IRQHandler from startup_stm32f103xe.o(.text) referenced from startup_stm32f103xe.o(RESET)
- DMA1_Channel2_IRQHandler from startup_stm32f103xe.o(.text) referenced from startup_stm32f103xe.o(RESET)
- DMA1_Channel3_IRQHandler from startup_stm32f103xe.o(.text) referenced from startup_stm32f103xe.o(RESET)
- DMA1_Channel4_IRQHandler from startup_stm32f103xe.o(.text) referenced from startup_stm32f103xe.o(RESET)
- DMA1_Channel5_IRQHandler from startup_stm32f103xe.o(.text) referenced from startup_stm32f103xe.o(RESET)
- DMA1_Channel6_IRQHandler from startup_stm32f103xe.o(.text) referenced from startup_stm32f103xe.o(RESET)
- DMA1_Channel7_IRQHandler from startup_stm32f103xe.o(.text) referenced from startup_stm32f103xe.o(RESET)
- DMA2_Channel1_IRQHandler from startup_stm32f103xe.o(.text) referenced from startup_stm32f103xe.o(RESET)
- DMA2_Channel2_IRQHandler from startup_stm32f103xe.o(.text) referenced from startup_stm32f103xe.o(RESET)
- DMA2_Channel3_IRQHandler from startup_stm32f103xe.o(.text) referenced from startup_stm32f103xe.o(RESET)
- DMA2_Channel4_5_IRQHandler from startup_stm32f103xe.o(.text) referenced from startup_stm32f103xe.o(RESET)
- DebugMon_Handler from stm32f1xx_it.o(i.DebugMon_Handler) referenced from startup_stm32f103xe.o(RESET)
- EXTI0_IRQHandler from startup_stm32f103xe.o(.text) referenced from startup_stm32f103xe.o(RESET)
- EXTI15_10_IRQHandler from startup_stm32f103xe.o(.text) referenced from startup_stm32f103xe.o(RESET)
- EXTI1_IRQHandler from startup_stm32f103xe.o(.text) referenced from startup_stm32f103xe.o(RESET)
- EXTI2_IRQHandler from startup_stm32f103xe.o(.text) referenced from startup_stm32f103xe.o(RESET)
- EXTI3_IRQHandler from startup_stm32f103xe.o(.text) referenced from startup_stm32f103xe.o(RESET)
- EXTI4_IRQHandler from startup_stm32f103xe.o(.text) referenced from startup_stm32f103xe.o(RESET)
- EXTI9_5_IRQHandler from startup_stm32f103xe.o(.text) referenced from startup_stm32f103xe.o(RESET)
- FLASH_IRQHandler from startup_stm32f103xe.o(.text) referenced from startup_stm32f103xe.o(RESET)
- FSMC_IRQHandler from startup_stm32f103xe.o(.text) referenced from startup_stm32f103xe.o(RESET)
- HardFault_Handler from stm32f1xx_it.o(i.HardFault_Handler) referenced from startup_stm32f103xe.o(RESET)
- I2C1_ER_IRQHandler from startup_stm32f103xe.o(.text) referenced from startup_stm32f103xe.o(RESET)
- I2C1_EV_IRQHandler from startup_stm32f103xe.o(.text) referenced from startup_stm32f103xe.o(RESET)
- I2C2_ER_IRQHandler from startup_stm32f103xe.o(.text) referenced from startup_stm32f103xe.o(RESET)
- I2C2_EV_IRQHandler from startup_stm32f103xe.o(.text) referenced from startup_stm32f103xe.o(RESET)
- MemManage_Handler from stm32f1xx_it.o(i.MemManage_Handler) referenced from startup_stm32f103xe.o(RESET)
- NMI_Handler from stm32f1xx_it.o(i.NMI_Handler) referenced from startup_stm32f103xe.o(RESET)
- PVD_IRQHandler from startup_stm32f103xe.o(.text) referenced from startup_stm32f103xe.o(RESET)
- PendSV_Handler from stm32f1xx_it.o(i.PendSV_Handler) referenced from startup_stm32f103xe.o(RESET)
- RCC_IRQHandler from startup_stm32f103xe.o(.text) referenced from startup_stm32f103xe.o(RESET)
- RTC_Alarm_IRQHandler from startup_stm32f103xe.o(.text) referenced from startup_stm32f103xe.o(RESET)
- RTC_IRQHandler from startup_stm32f103xe.o(.text) referenced from startup_stm32f103xe.o(RESET)
- Reset_Handler from startup_stm32f103xe.o(.text) referenced from startup_stm32f103xe.o(RESET)
- SDIO_IRQHandler from startup_stm32f103xe.o(.text) referenced from startup_stm32f103xe.o(RESET)
- SPI1_IRQHandler from startup_stm32f103xe.o(.text) referenced from startup_stm32f103xe.o(RESET)
- SPI2_IRQHandler from startup_stm32f103xe.o(.text) referenced from startup_stm32f103xe.o(RESET)
- SPI3_IRQHandler from startup_stm32f103xe.o(.text) referenced from startup_stm32f103xe.o(RESET)
- SVC_Handler from stm32f1xx_it.o(i.SVC_Handler) referenced from startup_stm32f103xe.o(RESET)
- SysTick_Handler from stm32f1xx_it.o(i.SysTick_Handler) referenced from startup_stm32f103xe.o(RESET)
- SystemInit from system_stm32f1xx.o(i.SystemInit) referenced from startup_stm32f103xe.o(.text)
- TAMPER_IRQHandler from startup_stm32f103xe.o(.text) referenced from startup_stm32f103xe.o(RESET)
- TIM1_BRK_IRQHandler from startup_stm32f103xe.o(.text) referenced from startup_stm32f103xe.o(RESET)
- TIM1_CC_IRQHandler from startup_stm32f103xe.o(.text) referenced from startup_stm32f103xe.o(RESET)
- TIM1_TRG_COM_IRQHandler from startup_stm32f103xe.o(.text) referenced from startup_stm32f103xe.o(RESET)
- TIM1_UP_IRQHandler from startup_stm32f103xe.o(.text) referenced from startup_stm32f103xe.o(RESET)
- TIM2_IRQHandler from startup_stm32f103xe.o(.text) referenced from startup_stm32f103xe.o(RESET)
- TIM3_IRQHandler from startup_stm32f103xe.o(.text) referenced from startup_stm32f103xe.o(RESET)
- TIM4_IRQHandler from startup_stm32f103xe.o(.text) referenced from startup_stm32f103xe.o(RESET)
- TIM5_IRQHandler from startup_stm32f103xe.o(.text) referenced from startup_stm32f103xe.o(RESET)
- TIM6_IRQHandler from startup_stm32f103xe.o(.text) referenced from startup_stm32f103xe.o(RESET)
- TIM7_IRQHandler from startup_stm32f103xe.o(.text) referenced from startup_stm32f103xe.o(RESET)
- TIM8_BRK_IRQHandler from startup_stm32f103xe.o(.text) referenced from startup_stm32f103xe.o(RESET)
- TIM8_CC_IRQHandler from startup_stm32f103xe.o(.text) referenced from startup_stm32f103xe.o(RESET)
- TIM8_TRG_COM_IRQHandler from startup_stm32f103xe.o(.text) referenced from startup_stm32f103xe.o(RESET)
- TIM8_UP_IRQHandler from startup_stm32f103xe.o(.text) referenced from startup_stm32f103xe.o(RESET)
- UART4_IRQHandler from startup_stm32f103xe.o(.text) referenced from startup_stm32f103xe.o(RESET)
- UART5_IRQHandler from startup_stm32f103xe.o(.text) referenced from startup_stm32f103xe.o(RESET)
- USART1_IRQHandler from startup_stm32f103xe.o(.text) referenced from startup_stm32f103xe.o(RESET)
- USART2_IRQHandler from startup_stm32f103xe.o(.text) referenced from startup_stm32f103xe.o(RESET)
- USART3_IRQHandler from startup_stm32f103xe.o(.text) referenced from startup_stm32f103xe.o(RESET)
- USBWakeUp_IRQHandler from startup_stm32f103xe.o(.text) referenced from startup_stm32f103xe.o(RESET)
- USB_HP_CAN1_TX_IRQHandler from startup_stm32f103xe.o(.text) referenced from startup_stm32f103xe.o(RESET)
- USB_LP_CAN1_RX0_IRQHandler from startup_stm32f103xe.o(.text) referenced from startup_stm32f103xe.o(RESET)
- UsageFault_Handler from stm32f1xx_it.o(i.UsageFault_Handler) referenced from startup_stm32f103xe.o(RESET)
- WWDG_IRQHandler from startup_stm32f103xe.o(.text) referenced from startup_stm32f103xe.o(RESET)
- __main from __main.o(!!!main) referenced from startup_stm32f103xe.o(.text)

### Global Symbols

__main (Thumb, 8 bytes, Stack size 0 bytes, __main.o(!!!main))

[Calls]

- >> __scatterload
- >> __rt_entry

__scatterload (Thumb, 0 bytes, Stack size unknown bytes, __scatter.o(!!!scatter))

[Called By]

- >> __main

__scatterload_rt2 (Thumb, 44 bytes, Stack size unknown bytes, __scatter.o(!!!scatter), UNUSED)

[Calls]

- >> __rt_entry

__scatterload_rt2_thumb_only (Thumb, 0 bytes, Stack size unknown bytes, __scatter.o(!!!scatter), UNUSED)

__scatterload_null (Thumb, 0 bytes, Stack size unknown bytes, __scatter.o(!!!scatter), UNUSED)

__scatterload_copy (Thumb, 26 bytes, Stack size unknown bytes, __scatter_copy.o(!!handler_copy), UNUSED)

[Calls]

- >> __scatterload_copy

[Called By]

- >> __scatterload_copy

__scatterload_zeroinit (Thumb, 28 bytes, Stack size unknown bytes, __scatter_zi.o(!!handler_zi), UNUSED)

__rt_lib_init (Thumb, 0 bytes, Stack size unknown bytes, libinit.o(.ARM.Collect$$libinit$$00000000))

[Called By]

- >> __rt_entry_li

__rt_lib_init_alloca_1 (Thumb, 0 bytes, Stack size unknown bytes, libinit2.o(.ARM.Collect$$libinit$$0000002E))

__rt_lib_init_argv_1 (Thumb, 0 bytes, Stack size unknown bytes, libinit2.o(.ARM.Collect$$libinit$$0000002C))

__rt_lib_init_atexit_1 (Thumb, 0 bytes, Stack size unknown bytes, libinit2.o(.ARM.Collect$$libinit$$0000001B))

__rt_lib_init_clock_1 (Thumb, 0 bytes, Stack size unknown bytes, libinit2.o(.ARM.Collect$$libinit$$00000021))

__rt_lib_init_cpp_1 (Thumb, 0 bytes, Stack size unknown bytes, libinit2.o(.ARM.Collect$$libinit$$00000032))

__rt_lib_init_exceptions_1 (Thumb, 0 bytes, Stack size unknown bytes, libinit2.o(.ARM.Collect$$libinit$$00000030))

__rt_lib_init_fp_1 (Thumb, 0 bytes, Stack size unknown bytes, libinit2.o(.ARM.Collect$$libinit$$00000002))

__rt_lib_init_fp_trap_1 (Thumb, 0 bytes, Stack size unknown bytes, libinit2.o(.ARM.Collect$$libinit$$0000001F))

__rt_lib_init_getenv_1 (Thumb, 0 bytes, Stack size unknown bytes, libinit2.o(.ARM.Collect$$libinit$$00000023))

__rt_lib_init_heap_1 (Thumb, 0 bytes, Stack size unknown bytes, libinit2.o(.ARM.Collect$$libinit$$0000000A))

__rt_lib_init_lc_collate_1 (Thumb, 0 bytes, Stack size unknown bytes, libinit2.o(.ARM.Collect$$libinit$$00000011))

__rt_lib_init_lc_ctype_1 (Thumb, 0 bytes, Stack size unknown bytes, libinit2.o(.ARM.Collect$$libinit$$00000013))

__rt_lib_init_lc_monetary_1 (Thumb, 0 bytes, Stack size unknown bytes, libinit2.o(.ARM.Collect$$libinit$$00000015))

__rt_lib_init_lc_numeric_1 (Thumb, 0 bytes, Stack size unknown bytes, libinit2.o(.ARM.Collect$$libinit$$00000017))

__rt_lib_init_lc_time_1 (Thumb, 0 bytes, Stack size unknown bytes, libinit2.o(.ARM.Collect$$libinit$$00000019))

__rt_lib_init_preinit_1 (Thumb, 0 bytes, Stack size unknown bytes, libinit2.o(.ARM.Collect$$libinit$$00000004))

__rt_lib_init_rand_1 (Thumb, 0 bytes, Stack size unknown bytes, libinit2.o(.ARM.Collect$$libinit$$0000000E))

__rt_lib_init_return (Thumb, 0 bytes, Stack size unknown bytes, libinit2.o(.ARM.Collect$$libinit$$00000033))

__rt_lib_init_signal_1 (Thumb, 0 bytes, Stack size unknown bytes, libinit2.o(.ARM.Collect$$libinit$$0000001D))

__rt_lib_init_stdio_1 (Thumb, 0 bytes, Stack size unknown bytes, libinit2.o(.ARM.Collect$$libinit$$00000025))

__rt_lib_init_user_alloc_1 (Thumb, 0 bytes, Stack size unknown bytes, libinit2.o(.ARM.Collect$$libinit$$0000000C))

__rt_lib_shutdown (Thumb, 0 bytes, Stack size unknown bytes, libshutdown.o(.ARM.Collect$$libshutdown$$00000000))

[Called By]

- >> __rt_exit_ls

__rt_lib_shutdown_cpp_1 (Thumb, 0 bytes, Stack size unknown bytes, libshutdown2.o(.ARM.Collect$$libshutdown$$00000002))

__rt_lib_shutdown_fp_trap_1 (Thumb, 0 bytes, Stack size unknown bytes, libshutdown2.o(.ARM.Collect$$libshutdown$$00000007))

__rt_lib_shutdown_heap_1 (Thumb, 0 bytes, Stack size unknown bytes, libshutdown2.o(.ARM.Collect$$libshutdown$$0000000F))

__rt_lib_shutdown_return (Thumb, 0 bytes, Stack size unknown bytes, libshutdown2.o(.ARM.Collect$$libshutdown$$00000010))

__rt_lib_shutdown_signal_1 (Thumb, 0 bytes, Stack size unknown bytes, libshutdown2.o(.ARM.Collect$$libshutdown$$0000000A))

__rt_lib_shutdown_stdio_1 (Thumb, 0 bytes, Stack size unknown bytes, libshutdown2.o(.ARM.Collect$$libshutdown$$00000004))

__rt_lib_shutdown_user_alloc_1 (Thumb, 0 bytes, Stack size unknown bytes, libshutdown2.o(.ARM.Collect$$libshutdown$$0000000C))

__rt_entry (Thumb, 0 bytes, Stack size unknown bytes, __rtentry.o(.ARM.Collect$$rtentry$$00000000))

[Called By]

- >> __scatterload_rt2
- >> __main

__rt_entry_presh_1 (Thumb, 0 bytes, Stack size unknown bytes, __rtentry2.o(.ARM.Collect$$rtentry$$00000002))

__rt_entry_sh (Thumb, 0 bytes, Stack size unknown bytes, __rtentry4.o(.ARM.Collect$$rtentry$$00000004))

[Stack]

- Max Depth = 8 + Unknown Stack Size
- Call Chain = __rt_entry_sh ⇒ __user_setup_stackheap

[Calls]

- >> __user_setup_stackheap

__rt_entry_li (Thumb, 0 bytes, Stack size unknown bytes, __rtentry2.o(.ARM.Collect$$rtentry$$0000000A))

[Calls]

- >> __rt_lib_init

__rt_entry_postsh_1 (Thumb, 0 bytes, Stack size unknown bytes, __rtentry2.o(.ARM.Collect$$rtentry$$00000009))

__rt_entry_main (Thumb, 0 bytes, Stack size unknown bytes, __rtentry2.o(.ARM.Collect$$rtentry$$0000000D))

[Stack]

- Max Depth = 160 + Unknown Stack Size
- Call Chain = __rt_entry_main ⇒ main ⇒ MX_TIM1_Init ⇒ HAL_TIM_MspPostInit ⇒ HAL_GPIO_Init

[Calls]

- >> main
- >> exit

__rt_entry_postli_1 (Thumb, 0 bytes, Stack size unknown bytes, __rtentry2.o(.ARM.Collect$$rtentry$$0000000C))

__rt_exit (Thumb, 0 bytes, Stack size unknown bytes, rtexit.o(.ARM.Collect$$rtexit$$00000000))

[Called By]

- >> exit

__rt_exit_ls (Thumb, 0 bytes, Stack size unknown bytes, rtexit2.o(.ARM.Collect$$rtexit$$00000003))

[Calls]

- >> __rt_lib_shutdown

__rt_exit_prels_1 (Thumb, 0 bytes, Stack size unknown bytes, rtexit2.o(.ARM.Collect$$rtexit$$00000002))

__rt_exit_exit (Thumb, 0 bytes, Stack size unknown bytes, rtexit2.o(.ARM.Collect$$rtexit$$00000004))

[Calls]

- >> _sys_exit

Reset_Handler (Thumb, 8 bytes, Stack size 0 bytes, startup_stm32f103xe.o(.text))
[Address Reference Count : 1]

- startup_stm32f103xe.o(RESET)

ADC1_2_IRQHandler (Thumb, 0 bytes, Stack size 0 bytes, startup_stm32f103xe.o(.text))

[Calls]

- >> ADC1_2_IRQHandler

[Called By]

- >> ADC1_2_IRQHandler

[Address Reference Count : 1]

- startup_stm32f103xe.o(RESET)

ADC3_IRQHandler (Thumb, 0 bytes, Stack size 0 bytes, startup_stm32f103xe.o(.text))
[Address Reference Count : 1]

- startup_stm32f103xe.o(RESET)

CAN1_RX1_IRQHandler (Thumb, 0 bytes, Stack size 0 bytes, startup_stm32f103xe.o(.text))
[Address Reference Count : 1]

- startup_stm32f103xe.o(RESET)

CAN1_SCE_IRQHandler (Thumb, 0 bytes, Stack size 0 bytes, startup_stm32f103xe.o(.text))
[Address Reference Count : 1]

- startup_stm32f103xe.o(RESET)

DMA1_Channel1_IRQHandler (Thumb, 0 bytes, Stack size 0 bytes, startup_stm32f103xe.o(.text))
[Address Reference Count : 1]

- startup_stm32f103xe.o(RESET)

DMA1_Channel2_IRQHandler (Thumb, 0 bytes, Stack size 0 bytes, startup_stm32f103xe.o(.text))
[Address Reference Count : 1]

- startup_stm32f103xe.o(RESET)

DMA1_Channel3_IRQHandler (Thumb, 0 bytes, Stack size 0 bytes, startup_stm32f103xe.o(.text))
[Address Reference Count : 1]

- startup_stm32f103xe.o(RESET)

DMA1_Channel4_IRQHandler (Thumb, 0 bytes, Stack size 0 bytes, startup_stm32f103xe.o(.text))
[Address Reference Count : 1]

- startup_stm32f103xe.o(RESET)

DMA1_Channel5_IRQHandler (Thumb, 0 bytes, Stack size 0 bytes, startup_stm32f103xe.o(.text))
[Address Reference Count : 1]

- startup_stm32f103xe.o(RESET)

DMA1_Channel6_IRQHandler (Thumb, 0 bytes, Stack size 0 bytes, startup_stm32f103xe.o(.text))
[Address Reference Count : 1]

- startup_stm32f103xe.o(RESET)

DMA1_Channel7_IRQHandler (Thumb, 0 bytes, Stack size 0 bytes, startup_stm32f103xe.o(.text))
[Address Reference Count : 1]

- startup_stm32f103xe.o(RESET)

DMA2_Channel1_IRQHandler (Thumb, 0 bytes, Stack size 0 bytes, startup_stm32f103xe.o(.text))
[Address Reference Count : 1]

- startup_stm32f103xe.o(RESET)

DMA2_Channel2_IRQHandler (Thumb, 0 bytes, Stack size 0 bytes, startup_stm32f103xe.o(.text))
[Address Reference Count : 1]

- startup_stm32f103xe.o(RESET)

DMA2_Channel3_IRQHandler (Thumb, 0 bytes, Stack size 0 bytes, startup_stm32f103xe.o(.text))
[Address Reference Count : 1]

- startup_stm32f103xe.o(RESET)

DMA2_Channel4_5_IRQHandler (Thumb, 0 bytes, Stack size 0 bytes, startup_stm32f103xe.o(.text))
[Address Reference Count : 1]

- startup_stm32f103xe.o(RESET)

EXTI0_IRQHandler (Thumb, 0 bytes, Stack size 0 bytes, startup_stm32f103xe.o(.text))
[Address Reference Count : 1]

- startup_stm32f103xe.o(RESET)

EXTI15_10_IRQHandler (Thumb, 0 bytes, Stack size 0 bytes, startup_stm32f103xe.o(.text))
[Address Reference Count : 1]

- startup_stm32f103xe.o(RESET)

EXTI1_IRQHandler (Thumb, 0 bytes, Stack size 0 bytes, startup_stm32f103xe.o(.text))
[Address Reference Count : 1]

- startup_stm32f103xe.o(RESET)

EXTI2_IRQHandler (Thumb, 0 bytes, Stack size 0 bytes, startup_stm32f103xe.o(.text))
[Address Reference Count : 1]

- startup_stm32f103xe.o(RESET)

EXTI3_IRQHandler (Thumb, 0 bytes, Stack size 0 bytes, startup_stm32f103xe.o(.text))
[Address Reference Count : 1]

- startup_stm32f103xe.o(RESET)

EXTI4_IRQHandler (Thumb, 0 bytes, Stack size 0 bytes, startup_stm32f103xe.o(.text))
[Address Reference Count : 1]

- startup_stm32f103xe.o(RESET)

EXTI9_5_IRQHandler (Thumb, 0 bytes, Stack size 0 bytes, startup_stm32f103xe.o(.text))
[Address Reference Count : 1]

- startup_stm32f103xe.o(RESET)

FLASH_IRQHandler (Thumb, 0 bytes, Stack size 0 bytes, startup_stm32f103xe.o(.text))
[Address Reference Count : 1]

- startup_stm32f103xe.o(RESET)

FSMC_IRQHandler (Thumb, 0 bytes, Stack size 0 bytes, startup_stm32f103xe.o(.text))
[Address Reference Count : 1]

- startup_stm32f103xe.o(RESET)

I2C1_ER_IRQHandler (Thumb, 0 bytes, Stack size 0 bytes, startup_stm32f103xe.o(.text))
[Address Reference Count : 1]

- startup_stm32f103xe.o(RESET)

I2C1_EV_IRQHandler (Thumb, 0 bytes, Stack size 0 bytes, startup_stm32f103xe.o(.text))
[Address Reference Count : 1]

- startup_stm32f103xe.o(RESET)

I2C2_ER_IRQHandler (Thumb, 0 bytes, Stack size 0 bytes, startup_stm32f103xe.o(.text))
[Address Reference Count : 1]

- startup_stm32f103xe.o(RESET)

I2C2_EV_IRQHandler (Thumb, 0 bytes, Stack size 0 bytes, startup_stm32f103xe.o(.text))
[Address Reference Count : 1]

- startup_stm32f103xe.o(RESET)

PVD_IRQHandler (Thumb, 0 bytes, Stack size 0 bytes, startup_stm32f103xe.o(.text))
[Address Reference Count : 1]

- startup_stm32f103xe.o(RESET)

RCC_IRQHandler (Thumb, 0 bytes, Stack size 0 bytes, startup_stm32f103xe.o(.text))
[Address Reference Count : 1]

- startup_stm32f103xe.o(RESET)

RTC_Alarm_IRQHandler (Thumb, 0 bytes, Stack size 0 bytes, startup_stm32f103xe.o(.text))
[Address Reference Count : 1]

- startup_stm32f103xe.o(RESET)

RTC_IRQHandler (Thumb, 0 bytes, Stack size 0 bytes, startup_stm32f103xe.o(.text))
[Address Reference Count : 1]

- startup_stm32f103xe.o(RESET)

SDIO_IRQHandler (Thumb, 0 bytes, Stack size 0 bytes, startup_stm32f103xe.o(.text))
[Address Reference Count : 1]

- startup_stm32f103xe.o(RESET)

SPI1_IRQHandler (Thumb, 0 bytes, Stack size 0 bytes, startup_stm32f103xe.o(.text))
[Address Reference Count : 1]

- startup_stm32f103xe.o(RESET)

SPI2_IRQHandler (Thumb, 0 bytes, Stack size 0 bytes, startup_stm32f103xe.o(.text))
[Address Reference Count : 1]

- startup_stm32f103xe.o(RESET)

SPI3_IRQHandler (Thumb, 0 bytes, Stack size 0 bytes, startup_stm32f103xe.o(.text))
[Address Reference Count : 1]

- startup_stm32f103xe.o(RESET)

TAMPER_IRQHandler (Thumb, 0 bytes, Stack size 0 bytes, startup_stm32f103xe.o(.text))
[Address Reference Count : 1]

- startup_stm32f103xe.o(RESET)

TIM1_BRK_IRQHandler (Thumb, 0 bytes, Stack size 0 bytes, startup_stm32f103xe.o(.text))
[Address Reference Count : 1]

- startup_stm32f103xe.o(RESET)

TIM1_CC_IRQHandler (Thumb, 0 bytes, Stack size 0 bytes, startup_stm32f103xe.o(.text))
[Address Reference Count : 1]

- startup_stm32f103xe.o(RESET)

TIM1_TRG_COM_IRQHandler (Thumb, 0 bytes, Stack size 0 bytes, startup_stm32f103xe.o(.text))
[Address Reference Count : 1]

- startup_stm32f103xe.o(RESET)

TIM1_UP_IRQHandler (Thumb, 0 bytes, Stack size 0 bytes, startup_stm32f103xe.o(.text))
[Address Reference Count : 1]

- startup_stm32f103xe.o(RESET)

TIM2_IRQHandler (Thumb, 0 bytes, Stack size 0 bytes, startup_stm32f103xe.o(.text))
[Address Reference Count : 1]

- startup_stm32f103xe.o(RESET)

TIM3_IRQHandler (Thumb, 0 bytes, Stack size 0 bytes, startup_stm32f103xe.o(.text))
[Address Reference Count : 1]

- startup_stm32f103xe.o(RESET)

TIM4_IRQHandler (Thumb, 0 bytes, Stack size 0 bytes, startup_stm32f103xe.o(.text))
[Address Reference Count : 1]

- startup_stm32f103xe.o(RESET)

TIM5_IRQHandler (Thumb, 0 bytes, Stack size 0 bytes, startup_stm32f103xe.o(.text))
[Address Reference Count : 1]

- startup_stm32f103xe.o(RESET)

TIM6_IRQHandler (Thumb, 0 bytes, Stack size 0 bytes, startup_stm32f103xe.o(.text))
[Address Reference Count : 1]

- startup_stm32f103xe.o(RESET)

TIM7_IRQHandler (Thumb, 0 bytes, Stack size 0 bytes, startup_stm32f103xe.o(.text))
[Address Reference Count : 1]

- startup_stm32f103xe.o(RESET)

TIM8_BRK_IRQHandler (Thumb, 0 bytes, Stack size 0 bytes, startup_stm32f103xe.o(.text))
[Address Reference Count : 1]

- startup_stm32f103xe.o(RESET)

TIM8_CC_IRQHandler (Thumb, 0 bytes, Stack size 0 bytes, startup_stm32f103xe.o(.text))
[Address Reference Count : 1]

- startup_stm32f103xe.o(RESET)

TIM8_TRG_COM_IRQHandler (Thumb, 0 bytes, Stack size 0 bytes, startup_stm32f103xe.o(.text))
[Address Reference Count : 1]

- startup_stm32f103xe.o(RESET)

TIM8_UP_IRQHandler (Thumb, 0 bytes, Stack size 0 bytes, startup_stm32f103xe.o(.text))
[Address Reference Count : 1]

- startup_stm32f103xe.o(RESET)

UART4_IRQHandler (Thumb, 0 bytes, Stack size 0 bytes, startup_stm32f103xe.o(.text))
[Address Reference Count : 1]

- startup_stm32f103xe.o(RESET)

UART5_IRQHandler (Thumb, 0 bytes, Stack size 0 bytes, startup_stm32f103xe.o(.text))
[Address Reference Count : 1]

- startup_stm32f103xe.o(RESET)

USART1_IRQHandler (Thumb, 0 bytes, Stack size 0 bytes, startup_stm32f103xe.o(.text))
[Address Reference Count : 1]

- startup_stm32f103xe.o(RESET)

USART2_IRQHandler (Thumb, 0 bytes, Stack size 0 bytes, startup_stm32f103xe.o(.text))
[Address Reference Count : 1]

- startup_stm32f103xe.o(RESET)

USART3_IRQHandler (Thumb, 0 bytes, Stack size 0 bytes, startup_stm32f103xe.o(.text))
[Address Reference Count : 1]

- startup_stm32f103xe.o(RESET)

USBWakeUp_IRQHandler (Thumb, 0 bytes, Stack size 0 bytes, startup_stm32f103xe.o(.text))
[Address Reference Count : 1]

- startup_stm32f103xe.o(RESET)

USB_HP_CAN1_TX_IRQHandler (Thumb, 0 bytes, Stack size 0 bytes, startup_stm32f103xe.o(.text))
[Address Reference Count : 1]

- startup_stm32f103xe.o(RESET)

USB_LP_CAN1_RX0_IRQHandler (Thumb, 0 bytes, Stack size 0 bytes, startup_stm32f103xe.o(.text))
[Address Reference Count : 1]

- startup_stm32f103xe.o(RESET)

WWDG_IRQHandler (Thumb, 0 bytes, Stack size 0 bytes, startup_stm32f103xe.o(.text))
[Address Reference Count : 1]

- startup_stm32f103xe.o(RESET)

__user_initial_stackheap (Thumb, 0 bytes, Stack size unknown bytes, startup_stm32f103xe.o(.text))

[Called By]

- >> __user_setup_stackheap

strlen (Thumb, 62 bytes, Stack size 8 bytes, strlen.o(.text))

[Stack]

- Max Depth = 8
- Call Chain = strlen

[Called By]

- >> UART_SendString

__aeabi_memclr4 (Thumb, 0 bytes, Stack size 4 bytes, rt_memclr_w.o(.text))

[Stack]

- Max Depth = 4
- Call Chain = __aeabi_memclr4

[Called By]

- >> SystemClock_Config
- >> MX_TIM1_Init

__aeabi_memclr8 (Thumb, 0 bytes, Stack size 4 bytes, rt_memclr_w.o(.text), UNUSED)

__rt_memclr_w (Thumb, 78 bytes, Stack size 4 bytes, rt_memclr_w.o(.text), UNUSED)

_memset_w (Thumb, 0 bytes, Stack size unknown bytes, rt_memclr_w.o(.text), UNUSED)

__use_two_region_memory (Thumb, 2 bytes, Stack size 0 bytes, heapauxi.o(.text), UNUSED)
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

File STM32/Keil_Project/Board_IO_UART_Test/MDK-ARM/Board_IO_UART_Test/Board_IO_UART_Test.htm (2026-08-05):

# Static Call Graph for image Board_IO_UART_Test\Board_IO_UART_Test.axf

#<CALLGRAPH># ARM Linker, 5060528: Last Updated: Wed Aug 05 22:33:25 2026

### Maximum Stack Usage = 136 bytes + Unknown(Functions without stacksize, Cycles, Untraceable Function Pointers)

### Call chain for Maximum Stack Depth:

__rt_entry_main ⇒ main ⇒ SystemClock_Config ⇒ HAL_RCC_ClockConfig ⇒ HAL_InitTick ⇒ HAL_NVIC_SetPriority

### Functions with no stack information

- __user_initial_stackheap

### Mutually Recursive functions

- ADC1_2_IRQHandler ⇒ ADC1_2_IRQHandler
- BusFault_Handler ⇒ BusFault_Handler
- HardFault_Handler ⇒ HardFault_Handler
- MemManage_Handler ⇒ MemManage_Handler
- NMI_Handler ⇒ NMI_Handler
- UsageFault_Handler ⇒ UsageFault_Handler
- UART_EndRxTransfer ⇒ UART_EndRxTransfer

### Function Pointers

- ADC1_2_IRQHandler from startup_stm32f103xe.o(.text) referenced from startup_stm32f103xe.o(RESET)
- ADC3_IRQHandler from startup_stm32f103xe.o(.text) referenced from startup_stm32f103xe.o(RESET)
- BusFault_Handler from stm32f1xx_it.o(i.BusFault_Handler) referenced from startup_stm32f103xe.o(RESET)
- CAN1_RX1_IRQHandler from startup_stm32f103xe.o(.text) referenced from startup_stm32f103xe.o(RESET)
- CAN1_SCE_IRQHandler from startup_stm32f103xe.o(.text) referenced from startup_stm32f103xe.o(RESET)
- DMA1_Channel1_IRQHandler from startup_stm32f103xe.o(.text) referenced from startup_stm32f103xe.o(RESET)
- DMA1_Channel2_IRQHandler from startup_stm32f103xe.o(.text) referenced from startup_stm32f103xe.o(RESET)
- DMA1_Channel3_IRQHandler from startup_stm32f103xe.o(.text) referenced from startup_stm32f103xe.o(RESET)
- DMA1_Channel4_IRQHandler from startup_stm32f103xe.o(.text) referenced from startup_stm32f103xe.o(RESET)
- DMA1_Channel5_IRQHandler from startup_stm32f103xe.o(.text) referenced from startup_stm32f103xe.o(RESET)
- DMA1_Channel6_IRQHandler from startup_stm32f103xe.o(.text) referenced from startup_stm32f103xe.o(RESET)
- DMA1_Channel7_IRQHandler from startup_stm32f103xe.o(.text) referenced from startup_stm32f103xe.o(RESET)
- DMA2_Channel1_IRQHandler from startup_stm32f103xe.o(.text) referenced from startup_stm32f103xe.o(RESET)
- DMA2_Channel2_IRQHandler from startup_stm32f103xe.o(.text) referenced from startup_stm32f103xe.o(RESET)
- DMA2_Channel3_IRQHandler from startup_stm32f103xe.o(.text) referenced from startup_stm32f103xe.o(RESET)
- DMA2_Channel4_5_IRQHandler from startup_stm32f103xe.o(.text) referenced from startup_stm32f103xe.o(RESET)
- DebugMon_Handler from stm32f1xx_it.o(i.DebugMon_Handler) referenced from startup_stm32f103xe.o(RESET)
- EXTI0_IRQHandler from startup_stm32f103xe.o(.text) referenced from startup_stm32f103xe.o(RESET)
- EXTI15_10_IRQHandler from startup_stm32f103xe.o(.text) referenced from startup_stm32f103xe.o(RESET)
- EXTI1_IRQHandler from startup_stm32f103xe.o(.text) referenced from startup_stm32f103xe.o(RESET)
- EXTI2_IRQHandler from startup_stm32f103xe.o(.text) referenced from startup_stm32f103xe.o(RESET)
- EXTI3_IRQHandler from startup_stm32f103xe.o(.text) referenced from startup_stm32f103xe.o(RESET)
- EXTI4_IRQHandler from startup_stm32f103xe.o(.text) referenced from startup_stm32f103xe.o(RESET)
- EXTI9_5_IRQHandler from startup_stm32f103xe.o(.text) referenced from startup_stm32f103xe.o(RESET)
- FLASH_IRQHandler from startup_stm32f103xe.o(.text) referenced from startup_stm32f103xe.o(RESET)
- FSMC_IRQHandler from startup_stm32f103xe.o(.text) referenced from startup_stm32f103xe.o(RESET)
- HardFault_Handler from stm32f1xx_it.o(i.HardFault_Handler) referenced from startup_stm32f103xe.o(RESET)
- I2C1_ER_IRQHandler from startup_stm32f103xe.o(.text) referenced from startup_stm32f103xe.o(RESET)
- I2C1_EV_IRQHandler from startup_stm32f103xe.o(.text) referenced from startup_stm32f103xe.o(RESET)
- I2C2_ER_IRQHandler from startup_stm32f103xe.o(.text) referenced from startup_stm32f103xe.o(RESET)
- I2C2_EV_IRQHandler from startup_stm32f103xe.o(.text) referenced from startup_stm32f103xe.o(RESET)
- MemManage_Handler from stm32f1xx_it.o(i.MemManage_Handler) referenced from startup_stm32f103xe.o(RESET)
- NMI_Handler from stm32f1xx_it.o(i.NMI_Handler) referenced from startup_stm32f103xe.o(RESET)
- PVD_IRQHandler from startup_stm32f103xe.o(.text) referenced from startup_stm32f103xe.o(RESET)
- PendSV_Handler from stm32f1xx_it.o(i.PendSV_Handler) referenced from startup_stm32f103xe.o(RESET)
- RCC_IRQHandler from startup_stm32f103xe.o(.text) referenced from startup_stm32f103xe.o(RESET)
- RTC_Alarm_IRQHandler from startup_stm32f103xe.o(.text) referenced from startup_stm32f103xe.o(RESET)
- RTC_IRQHandler from startup_stm32f103xe.o(.text) referenced from startup_stm32f103xe.o(RESET)
- Reset_Handler from startup_stm32f103xe.o(.text) referenced from startup_stm32f103xe.o(RESET)
- SDIO_IRQHandler from startup_stm32f103xe.o(.text) referenced from startup_stm32f103xe.o(RESET)
- SPI1_IRQHandler from startup_stm32f103xe.o(.text) referenced from startup_stm32f103xe.o(RESET)
- SPI2_IRQHandler from startup_stm32f103xe.o(.text) referenced from startup_stm32f103xe.o(RESET)
- SPI3_IRQHandler from startup_stm32f103xe.o(.text) referenced from startup_stm32f103xe.o(RESET)
- SVC_Handler from stm32f1xx_it.o(i.SVC_Handler) referenced from startup_stm32f103xe.o(RESET)
- SysTick_Handler from stm32f1xx_it.o(i.SysTick_Handler) referenced from startup_stm32f103xe.o(RESET)
- SystemInit from system_stm32f1xx.o(i.SystemInit) referenced from startup_stm32f103xe.o(.text)
- TAMPER_IRQHandler from startup_stm32f103xe.o(.text) referenced from startup_stm32f103xe.o(RESET)
- TIM1_BRK_IRQHandler from startup_stm32f103xe.o(.text) referenced from startup_stm32f103xe.o(RESET)
- TIM1_CC_IRQHandler from startup_stm32f103xe.o(.text) referenced from startup_stm32f103xe.o(RESET)
- TIM1_TRG_COM_IRQHandler from startup_stm32f103xe.o(.text) referenced from startup_stm32f103xe.o(RESET)
- TIM1_UP_IRQHandler from startup_stm32f103xe.o(.text) referenced from startup_stm32f103xe.o(RESET)
- TIM2_IRQHandler from startup_stm32f103xe.o(.text) referenced from startup_stm32f103xe.o(RESET)
- TIM3_IRQHandler from startup_stm32f103xe.o(.text) referenced from startup_stm32f103xe.o(RESET)
- TIM4_IRQHandler from startup_stm32f103xe.o(.text) referenced from startup_stm32f103xe.o(RESET)
- TIM5_IRQHandler from startup_stm32f103xe.o(.text) referenced from startup_stm32f103xe.o(RESET)
- TIM6_IRQHandler from startup_stm32f103xe.o(.text) referenced from startup_stm32f103xe.o(RESET)
- TIM7_IRQHandler from startup_stm32f103xe.o(.text) referenced from startup_stm32f103xe.o(RESET)
- TIM8_BRK_IRQHandler from startup_stm32f103xe.o(.text) referenced from startup_stm32f103xe.o(RESET)
- TIM8_CC_IRQHandler from startup_stm32f103xe.o(.text) referenced from startup_stm32f103xe.o(RESET)
- TIM8_TRG_COM_IRQHandler from startup_stm32f103xe.o(.text) referenced from startup_stm32f103xe.o(RESET)
- TIM8_UP_IRQHandler from startup_stm32f103xe.o(.text) referenced from startup_stm32f103xe.o(RESET)
- UART4_IRQHandler from startup_stm32f103xe.o(.text) referenced from startup_stm32f103xe.o(RESET)
- UART5_IRQHandler from startup_stm32f103xe.o(.text) referenced from startup_stm32f103xe.o(RESET)
- USART1_IRQHandler from startup_stm32f103xe.o(.text) referenced from startup_stm32f103xe.o(RESET)
- USART2_IRQHandler from startup_stm32f103xe.o(.text) referenced from startup_stm32f103xe.o(RESET)
- USART3_IRQHandler from startup_stm32f103xe.o(.text) referenced from startup_stm32f103xe.o(RESET)
- USBWakeUp_IRQHandler from startup_stm32f103xe.o(.text) referenced from startup_stm32f103xe.o(RESET)
- USB_HP_CAN1_TX_IRQHandler from startup_stm32f103xe.o(.text) referenced from startup_stm32f103xe.o(RESET)
- USB_LP_CAN1_RX0_IRQHandler from startup_stm32f103xe.o(.text) referenced from startup_stm32f103xe.o(RESET)
- UsageFault_Handler from stm32f1xx_it.o(i.UsageFault_Handler) referenced from startup_stm32f103xe.o(RESET)
- WWDG_IRQHandler from startup_stm32f103xe.o(.text) referenced from startup_stm32f103xe.o(RESET)
- __main from __main.o(!!!main) referenced from startup_stm32f103xe.o(.text)
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

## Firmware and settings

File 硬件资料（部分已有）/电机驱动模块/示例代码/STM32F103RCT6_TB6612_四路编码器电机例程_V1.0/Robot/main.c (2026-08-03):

/**			                                                    
		   ____                    _____ _______ _____       XTARK@塔克创新
		  / __ \                  / ____|__   __|  __ \ 
		 | |  | |_ __   ___ _ __ | |       | |  | |__) |
		 | |  | | '_ \ / _ \ '_ \| |       | |  |  _  / 
		 | |__| | |_) |  __/ | | | |____   | |  | | \ \ 
		  \____/| .__/ \___|_| |_|\_____|  |_|  |_|  \_\
				| |                                     
				|_|                OpenCTR   机器人控制器
									 
  ****************************************************************************** 
  *           
  * 版权所有： XTARK@塔克创新  版权所有，盗版必究
  * 公司网站： www.xtark.cn   www.tarkbot.com
  * 淘宝店铺： https://xtark.taobao.com  
  * 塔克微信： 塔克创新（关注公众号，获取最新更新资讯）
  *           
  ******************************************************************************
  * @作  者  塔克创新团队
  * @内  容  TB6612四路编码器电机例程
  * 
  ******************************************************************************
  */ 


/* Includes ------------------------------------------------------------------*/
#include "stm32f10x.h"
#include <stdio.h>
#include <math.h>   


#include "ax_sys.h"    //系统设置
#include "ax_delay.h"  //软件延时
#include "ax_uart1.h"  //调试串口
#include "ax_vin.h"    //输入电压检测

#include "ax_motor.h"   //直流电机调速控制
#include "ax_encoder.h" //编码器控制

int16_t  encoder[4];	//编码器数值
uint16_t adc_value;     //电压采集值

/**
  * @简  述  主程序
  * @参  数  无
  * @返回值  无
  */
int main(void)
{
	//软件延时初始化
	AX_DELAY_Init(); 	
	
	//调试串口初始化
	AX_UART1_Init(115200); //调试串口
	printf("  \r\n"); //输出空格，CPUBUG	
	
	printf("XTARK TB6612 四路编码器电机驱动例程 \r\n");  
	
	//JTAG口设置
	AX_JTAG_Set(JTAG_SWD_DISABLE);  //关闭JTAG接口 
	AX_JTAG_Set(SWD_ENABLE);  //打开SWD接口 可以利用主板的SWD接口调试 		
	
	//电机初始化
	AX_MOTOR_Init();
	
 	//正交编码器初始化
	AX_ENCODER_A_Init();  
	AX_ENCODER_B_Init(); 	
	AX_ENCODER_C_Init();  
	AX_ENCODER_D_Init(); 

	//电压采样初始化
	AX_VIN_Init();
	
	while (1) 
	{		
		//控制电机转速，设置范围（±7200）
		AX_MOTOR_A_SetSpeed(-2000);
		AX_MOTOR_B_SetSpeed(-2000);
		AX_MOTOR_C_SetSpeed(-2000);
		AX_MOTOR_D_SetSpeed(-2000);
		
		//电机编码器采集
		encoder[0] = AX_ENCODER_A_GetCounter();
		encoder[1] = AX_ENCODER_B_GetCounter();
	    encoder[2] = AX_ENCODER_C_GetCounter();
		encoder[3] = AX_ENCODER_D_GetCounter();
		
		//设置编码器为0
		AX_ENCODER_A_SetCounter(0);  
		AX_ENCODER_B_SetCounter(0);	
		AX_ENCODER_C_SetCounter(0);  
		AX_ENCODER_D_SetCounter(0);	
		
		//输入电压采集，AD转换
		adc_value = AX_VIN_GetVol_X100();
		
		//串口输出内容，两个编码器数值和电压值
		printf("MA:%d  MB:%d  MC:%d  MD:%d  VIN:%d  \r\n",encoder[0], encoder[1], encoder[2], encoder[3], adc_value);  
		
		//延时
		AX_Delayms(100);
	}
}

/******************* (C) 版权 2026 XTARK **************************************/

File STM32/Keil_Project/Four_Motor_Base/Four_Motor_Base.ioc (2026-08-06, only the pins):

Mcu.UserName=STM32F103RCTx
PA0-WKUP.GPIO_Label=WK_UP
PA0-WKUP.Signal=GPIO_Input
PA1.Signal=S_TIM5_CH2
PA10.GPIO_Label=MOTOR_D_IN2
PA10.Signal=GPIO_Output
PA13.Signal=SYS_JTMS-SWDIO
PA14.Signal=SYS_JTCK-SWCLK
PA15.Signal=S_TIM2_CH1_ETR
PA2.Signal=S_TIM5_CH3
PA6.Signal=S_TIM3_CH1
PA7.Signal=S_TIM3_CH2
PA8.Signal=S_TIM1_CH1
PA9.Signal=S_TIM1_CH2
PB0.GPIO_Label=MOTOR_C_IN2
PB0.Signal=GPIO_Output
PB1.GPIO_Label=MOTOR_D_IN1
PB1.Signal=GPIO_Output
PB10.Signal=USART3_TX
PB11.Signal=USART3_RX
PB3.Signal=S_TIM2_CH2
PB6.Signal=S_TIM4_CH1
PB7.Signal=S_TIM4_CH2
PC0.GPIO_Label=MOTOR_A_IN1
PC0.Signal=GPIO_Output
PC1.GPIO_Label=MOTOR_A_IN2
PC1.Signal=GPIO_Output
PC2.GPIO_Label=MOTOR_STBY
PC2.Signal=GPIO_Output
PC3.GPIO_Label=MOTOR_B_IN1
PC3.Signal=GPIO_Output
PC4.GPIO_Label=MOTOR_B_IN2
PC4.Signal=GPIO_Output
PC5.GPIO_Label=MOTOR_C_IN1
PC5.Signal=GPIO_Output
PC6.Signal=S_TIM8_CH1
PC7.Signal=S_TIM8_CH2
PC8.GPIO_Label=KEY2
PC8.Signal=GPIO_Input
PC9.GPIO_Label=KEY1
PC9.Signal=GPIO_Input
PD0-OSC_IN.Signal=RCC_OSC_IN
PD1-OSC_OUT.Signal=RCC_OSC_OUT

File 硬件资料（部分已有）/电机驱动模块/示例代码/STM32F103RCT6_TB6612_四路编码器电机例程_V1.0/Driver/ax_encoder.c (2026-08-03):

/**			                                                    
		   ____                    _____ _____  _____        XTARK@塔克创新
		  / __ \                  / ____|  __ \|  __ \  
		 | |  | |_ __   ___ _ __ | |    | |__) | |__) |
		 | |  | | '_ \ / _ \ '_ \| |    |  _  /|  ___/ 
		 | |__| | |_) |  __/ | | | |____| | \ \| |     
		  \____/| .__/ \___|_| |_|\_____|_|  \_\_|     
		    	| |                                    
		    	|_|  OpenCRP 树莓派 专用ROS机器人控制器                                   
									 
  ****************************************************************************** 
  *           
  * 版权所有： XTARK@塔克创新  版权所有，盗版必究
  * 官网网站： www.xtark.cn
  * 淘宝店铺： https://shop246676508.taobao.com  
  * 塔克媒体： www.cnblogs.com/xtark（博客）
	* 塔克微信： 微信公众号：塔克创新（获取最新资讯）
  *      
  ******************************************************************************
  * @author  Musk Han @ XTARK
  * @brief   电机编码器
  *
  ******************************************************************************
  * @说  明
  *
  ******************************************************************************
  */

#include "ax_encoder.h" 

/**
  * @简  述  编码器AB初始化
  * @参  数  无
  * @返回值  无
  */
void AX_ENCODER_A_Init(void)
{ 
	GPIO_InitTypeDef GPIO_InitStructure; 
	TIM_TimeBaseInitTypeDef  TIM_TimeBaseStructure;
	TIM_ICInitTypeDef TIM_ICInitStructure;   

	//GPIO功能时钟使能
	RCC_APB2PeriphClockCmd(RCC_APB2Periph_GPIOA | RCC_APB2Periph_GPIOB | RCC_APB2Periph_AFIO, ENABLE);

	GPIO_PinRemapConfig(GPIO_FullRemap_TIM2, ENABLE);

	//配置IO口为复用功能-定时器通道
	GPIO_InitStructure.GPIO_Pin =  GPIO_Pin_3;
	GPIO_InitStructure.GPIO_Mode = GPIO_Mode_IN_FLOATING;        //复用功能
	GPIO_InitStructure.GPIO_Speed = GPIO_Speed_50MHz;	//速度100MHz
	GPIO_Init(GPIOB, &GPIO_InitStructure);

	GPIO_InitStructure.GPIO_Pin =  GPIO_Pin_15;
	GPIO_Init(GPIOA, &GPIO_InitStructure);

	//TIM时钟使能
	RCC_APB1PeriphClockCmd(RCC_APB1Periph_TIM2, ENABLE);

	//Timer configuration in Encoder mode 
	TIM_DeInit(TIM2);
	TIM_TimeBaseStructInit(&TIM_TimeBaseStructure);

	TIM_TimeBaseStructure.TIM_Prescaler = 0x0;  // No prescaling 
	TIM_TimeBaseStructure.TIM_Period = 0xFFFF;  
	TIM_TimeBaseStructure.TIM_ClockDivision = TIM_CKD_DIV1;
	TIM_TimeBaseStructure.TIM_CounterMode = TIM_CounterMode_Up;   
	TIM_TimeBaseInit(TIM2, &TIM_TimeBaseStructure);

	TIM_EncoderInterfaceConfig(TIM2, TIM_EncoderMode_TI12, TIM_ICPolarity_Rising, TIM_ICPolarity_Rising);
	TIM_ICStructInit(&TIM_ICInitStructure);
	TIM_ICInitStructure.TIM_ICFilter = 6;
	TIM_ICInit(TIM2, &TIM_ICInitStructure);

	//Reset counter
	TIM2->CNT = 0;

	TIM_Cmd(TIM2, ENABLE);   
}

/**
  * @简  述  编码器AB获取计数器数值
  * @参  数  无
  * @返回值  计数器当前值
  */
uint16_t AX_ENCODER_A_GetCounter(void)
{
	return TIM2->CNT;
}

/**
  * @简  述  编码器AB设置计数器数值
  * @参  数  count  计数器数值
  * @返回值  无
  */
void AX_ENCODER_A_SetCounter(uint16_t count)
{
	TIM2->CNT = count;
}

/**
  * @简  述  编码器CD初始化
  * @参  数  无
  * @返回值  无
  */
void AX_ENCODER_B_Init(void)
{ 
	GPIO_InitTypeDef GPIO_InitStructure; 
	TIM_TimeBaseInitTypeDef  TIM_TimeBaseStructure;
	TIM_ICInitTypeDef TIM_ICInitStructure;   

	//GPIO功能时钟使能
	RCC_APB2PeriphClockCmd(RCC_APB2Periph_GPIOB | RCC_APB2Periph_AFIO, ENABLE);

	//配置IO口为复用功能-定时器通道
	GPIO_InitStructure.GPIO_Pin =  GPIO_Pin_4 | GPIO_Pin_5;
	GPIO_InitStructure.GPIO_Mode = GPIO_Mode_IN_FLOATING;        //复用功能
	GPIO_InitStructure.GPIO_Speed = GPIO_Speed_50MHz;	//速度100MHz
	GPIO_Init(GPIOB, &GPIO_InitStructure);

	//TIM时钟使能
	RCC_APB1PeriphClockCmd(RCC_APB1Periph_TIM3, ENABLE);

	GPIO_PinRemapConfig(GPIO_PartialRemap_TIM3 , ENABLE); //这个就是重映射功能函数

	//Timer configuration in Encoder mode 
	TIM_DeInit(TIM3);
	TIM_TimeBaseStructInit(&TIM_TimeBaseStructure);

	TIM_TimeBaseStructure.TIM_Prescaler = 0x0;  // No prescaling 
	TIM_TimeBaseStructure.TIM_Period = 0xFFFF;  
	TIM_TimeBaseStructure.TIM_ClockDivision = TIM_CKD_DIV1;
	TIM_TimeBaseStructure.TIM_CounterMode = TIM_CounterMode_Up;   
	TIM_TimeBaseInit(TIM3, &TIM_TimeBaseStructure);

	TIM_EncoderInterfaceConfig(TIM3, TIM_EncoderMode_TI12, TIM_ICPolarity_Rising, TIM_ICPolarity_Rising);
	TIM_ICStructInit(&TIM_ICInitStructure);
	TIM_ICInitStructure.TIM_ICFilter = 6;
	TIM_ICInit(TIM3, &TIM_ICInitStructure);

	//Reset counter
	TIM3->CNT = 0;

	TIM_Cmd(TIM3, ENABLE);  
}

/**
  * @简  述  编码器CD获取计数器数值
  * @参  数  无
  * @返回值  计数器当前值
  */
uint16_t AX_ENCODER_B_GetCounter(void)
{
	return TIM3->CNT;
}

/**
  * @简  述  编码器CD设置计数器数值
  * @参  数  count  计数器数值
  * @返回值  无
  */
void AX_ENCODER_B_SetCounter(uint16_t count)
{
	TIM3->CNT = count;
}

/**
  * @简  述  编码器EF初始化
  * @参  数  无
  * @返回值  无
  */
void AX_ENCODER_C_Init(void)
{ 
	GPIO_InitTypeDef GPIO_InitStructure; 
	TIM_TimeBaseInitTypeDef  TIM_TimeBaseStructure;
	TIM_ICInitTypeDef TIM_ICInitStructure;   

	//GPIO功能时钟使能
	RCC_APB2PeriphClockCmd(RCC_APB2Periph_GPIOB, ENABLE);

	//配置IO口为复用功能-定时器通道
	GPIO_InitStructure.GPIO_Pin =  GPIO_Pin_6 | GPIO_Pin_7;
	GPIO_InitStructure.GPIO_Mode = GPIO_Mode_IN_FLOATING;        //复用功能
	GPIO_InitStructure.GPIO_Speed = GPIO_Speed_50MHz;	//速度100MHz
	GPIO_Init(GPIOB, &GPIO_InitStructure);

	//TIM时钟使能
	RCC_APB1PeriphClockCmd(RCC_APB1Periph_TIM4, ENABLE);

	//Timer configuration in Encoder mode 
	TIM_DeInit(TIM4);
	TIM_TimeBaseStructInit(&TIM_TimeBaseStructure);

	TIM_TimeBaseStructure.TIM_Prescaler = 0x0;  // No prescaling 
	TIM_TimeBaseStructure.TIM_Period = 0xFFFF;  
	TIM_TimeBaseStructure.TIM_ClockDivision = TIM_CKD_DIV1;
	TIM_TimeBaseStructure.TIM_CounterMode = TIM_CounterMode_Up;   
	TIM_TimeBaseInit(TIM4, &TIM_TimeBaseStructure);

	TIM_EncoderInterfaceConfig(TIM4, TIM_EncoderMode_TI12, TIM_ICPolarity_Rising, TIM_ICPolarity_Rising);
	TIM_ICStructInit(&TIM_ICInitStructure);
	TIM_ICInitStructure.TIM_ICFilter = 6;
	TIM_ICInit(TIM4, &TIM_ICInitStructure);

	//Reset counter
	TIM4->CNT = 0;

	TIM_Cmd(TIM4, ENABLE);     
}

/**
  * @简  述  编码器EF获取计数器数值
  * @参  数  无
  * @返回值  计数器当前值
  */
uint16_t AX_ENCODER_C_GetCounter(void)
{
	return TIM4->CNT;
}

/**
  * @简  述  编码器EF设置计数器数值
  * @参  数  count  计数器数值
  * @返回值  无
  */
void AX_ENCODER_C_SetCounter(uint16_t count)
{
	TIM4->CNT = count;
}
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

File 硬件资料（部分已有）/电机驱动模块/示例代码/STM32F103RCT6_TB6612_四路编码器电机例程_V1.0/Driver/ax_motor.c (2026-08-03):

/**			                                                    
		   ____                    _____ _____  _____        XTARK@塔克创新
		  / __ \                  / ____|  __ \|  __ \  
		 | |  | |_ __   ___ _ __ | |    | |__) | |__) |
		 | |  | | '_ \ / _ \ '_ \| |    |  _  /|  ___/ 
		 | |__| | |_) |  __/ | | | |____| | \ \| |     
		  \____/| .__/ \___|_| |_|\_____|_|  \_\_|     
		    	| |                                    
		    	|_|  OpenCRP 树莓派 专用ROS机器人控制器                                   
									 
  ****************************************************************************** 
  *           
  * 版权所有： XTARK@塔克创新  版权所有，盗版必究
  * 官网网站： www.xtark.cn
  * 淘宝店铺： https://shop246676508.taobao.com  
  * 塔克媒体： www.cnblogs.com/xtark（博客）
  * 塔克微信： 微信公众号：塔克创新（获取最新资讯）
  *      
  ******************************************************************************
  * @作  者  塔克创新团队
  * @brief   电机PWM控制函数
  *
  ******************************************************************************
  * @说  明
  *
  ******************************************************************************
  */

#include "ax_motor.h" 

/**
  * @简  述  电机PWM控制初始化，PWM频率为10KHZ	
  * @参  数  无
  * @返回值  无
  */
void AX_MOTOR_Init(void)
{ 
	
	GPIO_InitTypeDef GPIO_InitStructure; 
	TIM_TimeBaseInitTypeDef  TIM_TimeBaseStructure;
	TIM_OCInitTypeDef  TIM_OCInitStructure; 

	//定时器通道IO配置
	//GPIO及复用功能时钟使能
	RCC_APB2PeriphClockCmd(RCC_APB2Periph_GPIOC | RCC_APB2Periph_AFIO, ENABLE);	

	//配置IO口为复用功能-定时器通道
	GPIO_InitStructure.GPIO_Pin =  GPIO_Pin_6 | GPIO_Pin_7 | GPIO_Pin_8 | GPIO_Pin_9;
	GPIO_InitStructure.GPIO_Mode = GPIO_Mode_AF_PP;
	GPIO_InitStructure.GPIO_Speed = GPIO_Speed_50MHz;
	GPIO_Init(GPIOC, &GPIO_InitStructure);

	//电机方向控制IO配置
	//IO时钟使能
	RCC_APB2PeriphClockCmd(RCC_APB2Periph_GPIOB | RCC_APB2Periph_GPIOC, ENABLE);

	//电机A方向控制IO
	GPIO_InitStructure.GPIO_Pin = GPIO_Pin_15 | GPIO_Pin_13;
	GPIO_InitStructure.GPIO_Mode = GPIO_Mode_Out_PP;
	GPIO_InitStructure.GPIO_Speed = GPIO_Speed_50MHz;
	GPIO_Init(GPIOB, &GPIO_InitStructure);

	//电机B方向控制IO
	GPIO_InitStructure.GPIO_Pin = GPIO_Pin_14 | GPIO_Pin_12;
	GPIO_Init(GPIOB, &GPIO_InitStructure);

	//电机C方向控制IO
	GPIO_InitStructure.GPIO_Pin = GPIO_Pin_2 | GPIO_Pin_0;
	GPIO_Init(GPIOC, &GPIO_InitStructure);

	//电机D方向控制IO
	GPIO_InitStructure.GPIO_Pin = GPIO_Pin_3 | GPIO_Pin_1;
	GPIO_Init(GPIOC, &GPIO_InitStructure);

	//TIM时钟使能
	RCC_APB2PeriphClockCmd(RCC_APB2Periph_TIM8, ENABLE);

	//PWM频率为10KHZ，PWM占空比7200档可调
	TIM_TimeBaseStructure.TIM_Period = 7200-1;
	TIM_TimeBaseStructure.TIM_Prescaler = 0;
	TIM_TimeBaseStructure.TIM_ClockDivision = TIM_CKD_DIV1;//
	TIM_TimeBaseStructure.TIM_CounterMode = TIM_CounterMode_Up;
	TIM_TimeBaseInit(TIM8, &TIM_TimeBaseStructure);

	//PWM1 Mode configuration: Channel1 
	TIM_OCInitStructure.TIM_OCMode = TIM_OCMode_PWM1;
	TIM_OCInitStructure.TIM_OutputState = TIM_OutputState_Enable;
	TIM_OCInitStructure.TIM_Pulse = 0;	    //占空比初始化
	TIM_OCInitStructure.TIM_OCPolarity = TIM_OCPolarity_High;
	TIM_OC1Init(TIM8, &TIM_OCInitStructure);
	TIM_OC1PreloadConfig(TIM8, TIM_OCPreload_Enable);

	//PWM1 Mode configuration: Channel2
	TIM_OC2Init(TIM8, &TIM_OCInitStructure);
	TIM_OC2PreloadConfig(TIM8, TIM_OCPreload_Enable);

	//PWM1 Mode configuration: Channel3
	TIM_OC3Init(TIM8, &TIM_OCInitStructure);
	TIM_OC3PreloadConfig(TIM8, TIM_OCPreload_Enable);

	//PWM1 Mode configuration: Channel4
	TIM_OC4Init(TIM8, &TIM_OCInitStructure);
	TIM_OC4PreloadConfig(TIM8, TIM_OCPreload_Enable);

	TIM_ARRPreloadConfig(TIM8, ENABLE);

	//TIM enable counter
	TIM_Cmd(TIM8, ENABLE);   

	//使能MOE位
	TIM_CtrlPWMOutputs(TIM8,ENABLE);	
}

/**
  * @简  述 电机A PWM速度控制
  * @参  数 speed 电机转速数值，范围-7200~7200
  * @返回值 无
  */
void AX_MOTOR_A_SetSpeed(int16_t speed)
{
	uint16_t temp;

	if(speed > 0)
	{
		GPIO_ResetBits(GPIOB, GPIO_Pin_15);
	    GPIO_SetBits(GPIOB, GPIO_Pin_13);
		temp = speed;	
	}
	else if(speed < 0)
	{
		GPIO_ResetBits(GPIOB, GPIO_Pin_13);
		GPIO_SetBits(GPIOB, GPIO_Pin_15);
		temp = (-speed);
	}
	else
	{
		GPIO_ResetBits(GPIOB, GPIO_Pin_13);
		GPIO_ResetBits(GPIOB, GPIO_Pin_15);
		temp = 0;
	}

	if(temp>7200)
		temp = 7200;

	TIM_SetCompare1(TIM8,temp);
}

/**
  * @简  述 电机B PWM速度控制
  * @参  数 speed 电机转速数值，范围-7200~7200
  * @返回值 无
  */
void AX_MOTOR_B_SetSpeed(int16_t speed)
{
	uint16_t temp;

    if(speed > 0)
	{
		GPIO_ResetBits(GPIOB, GPIO_Pin_14);
	  GPIO_SetBits(GPIOB, GPIO_Pin_12);
		temp = speed;	
	}
	else if(speed < 0)
	{
		GPIO_ResetBits(GPIOB, GPIO_Pin_12);
	  GPIO_SetBits(GPIOB, GPIO_Pin_14);
		temp = (-speed);
	}
	else
	{
		GPIO_ResetBits(GPIOB, GPIO_Pin_12);
	  GPIO_ResetBits(GPIOB, GPIO_Pin_14);
		temp = 0;
	}
	
	if(temp>7200)
		temp = 7200;
	
	TIM_SetCompare2(TIM8,temp);
}
/**
  * @简  述 电机C PWM速度控制
  * @参  数 speed 电机转速数值，范围-7200~7200
  * @返回值 无
  */
void AX_MOTOR_C_SetSpeed(int16_t speed)
{
	uint16_t temp;

  if(speed > 0)
	{
		GPIO_ResetBits(GPIOC, GPIO_Pin_2);
	  GPIO_SetBits(GPIOC, GPIO_Pin_0);
		temp = speed;	
	}
	else if(speed < 0)
	{
		GPIO_ResetBits(GPIOC, GPIO_Pin_0);
	  GPIO_SetBits(GPIOC, GPIO_Pin_2);
		temp = (-speed);
	}
	else
	{
		GPIO_ResetBits(GPIOC, GPIO_Pin_2);
	  GPIO_ResetBits(GPIOC, GPIO_Pin_0);
		temp = 0;
	}
	
	if(temp>7200)
		temp = 7200;
	
	TIM_SetCompare3(TIM8,temp);
}

/**
  * @简  述 电机D PWM速度控制
  * @参  数 speed 电机转速数值，范围-7200~7200
  * @返回值 无
  */
void AX_MOTOR_D_SetSpeed(int16_t speed)
{
	uint16_t temp;

  if(speed > 0)
	{
		GPIO_ResetBits(GPIOC, GPIO_Pin_3);
	  GPIO_SetBits(GPIOC, GPIO_Pin_1);
		temp = speed;	
	}
	else if(speed < 0)
	{
		GPIO_ResetBits(GPIOC, GPIO_Pin_1);
	  GPIO_SetBits(GPIOC, GPIO_Pin_3);
		temp = (-speed);
	}
	else
	{
		GPIO_ResetBits(GPIOC, GPIO_Pin_1);
	  GPIO_ResetBits(GPIOC, GPIO_Pin_3);
		temp = 0;
	}
	
	if(temp>7200)
		temp = 7200;
	
	TIM_SetCompare4(TIM8,temp);
}



/******************* (C) 版权 2026 XTARK **************************************/

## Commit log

2026-08-01 创建Robot_Treasure项目结构
2026-08-01 添加STM32项目git忽略规则
2026-08-01 添加Git使用说明文档
2026-08-01 完善项目README文档
2026-08-02 更新比赛规则整理文档
2026-08-02 更新机器人硬件方案与系统设计文档
2026-08-02 Update README to remove specific technology references
    Removed mention of Jetson, camera vision, YOLO, or ROS from the README.
2026-08-02 更新R5四驱底盘方案与硬件采购状态
2026-08-03 完善整车硬件关联与NCHD12双模块方案
2026-08-03 硬件介绍更新
2026-08-03 整理硬件采购与资料链接
2026-08-03 重命名并更新硬件介绍文档
2026-08-03 对换硬件清单和硬件介绍文件名
2026-08-03 更新Docs/04_硬件介绍.md
2026-08-03 更新ToF敌方检测方案并整理AI-1811资料
    [6-主动上报模式-接收报文解析.xlsx]
2026-08-03 整理硬件参考资料并配置CAD模型二进制属性
    [37电机支架.STEP, MC520编码器电机模型.STEP, R5小车底板模型.STEP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]
2026-08-03 补充NCHD12和电机驱动参考例程
2026-08-03 添加团队任务表和Git协作教程
    [项目任务分工.xlsx]
2026-08-05 完成STM32开发环境搭建和LED点灯测试
2026-08-05 完成72MHz时钟、串口和板载按键测试
2026-08-05 完成TIM1 PWM和LED呼吸灯测试
2026-08-05 Add Motor A test project and development rules
2026-08-05 完成A路电机正反转和模块化控制测试
2026-08-05 完成A路电机编码器原始计数测试
2026-08-06 完成A路电机编码器RPM计算与测试
2026-08-06 完成A路电机PWM与RPM关系测试
2026-08-06 完成A路电机速度闭环PID测试
2026-08-06 修正PWM-RPM测试工程的ST-Link下载配置
2026-08-06 完成四路电机基础框架与A路迁移验证
2026-08-06 完成四路电机与编码器通道联合测试
2026-08-06 完成四轮底盘运动与方向映射测试
2026-08-06 完成四轮独立速度闭环控制与安全测试
2026-08-06 新增四电机落地直行测试工程
2026-08-06 添加项目问题记录和阶段总结
2026-08-06 完成12路灰度传感器I2C读取与通道映射验证
2026-08-06 docs: add hardware wiring and interface guide
2026-08-06 完成12路灰度位置与横向误差验证
2026-08-07 完成灰度车辆坐标验证并更新当前轮位
2026-08-07 完成新车头单轮方向与编码器符号验证
2026-08-07 完成新车头四轮PI落地直行验证
2026-08-08 完成11E单灰度P循迹验证并更新开发规范
2026-08-18 完成12B AI-1811激光测距基础读取测试
2026-08-18 完成12A普通红外传感器基础读取测试
2026-08-25 完成13A普通红外障碍触发后退联动测试
2026-09-08 完成14A循迹与红外障碍后退整合测试
2026-09-17 新增15B平顺循迹试验工程
2026-09-21 记录 JY61P UART5 接线
2026-09-22 新增 JY61P 90度转弯循迹试验工程
2026-09-28 更新四方向红外引脚规划
2026-09-28 保存已调参的 Gray12 双灰度循迹竞速基线
2026-10-03 docs: 添加小偷与警察夺宝对抗策略说明
2026-10-03 feat: 保存夺宝地图规划与双车追逃仿真最终成果
